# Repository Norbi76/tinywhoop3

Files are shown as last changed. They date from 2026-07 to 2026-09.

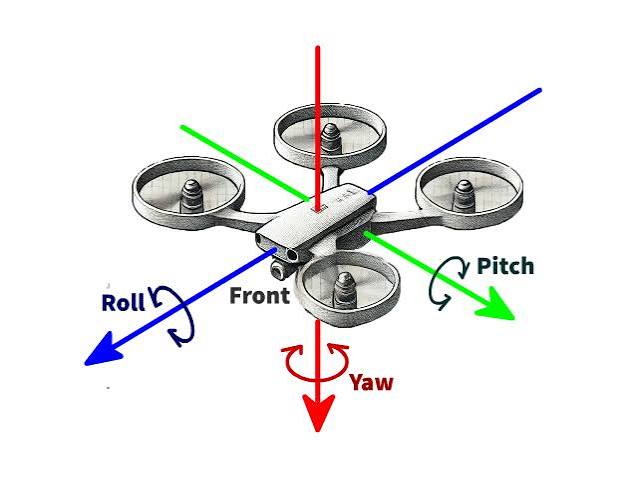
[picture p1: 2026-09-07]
documents/documentatie/images.jpeg

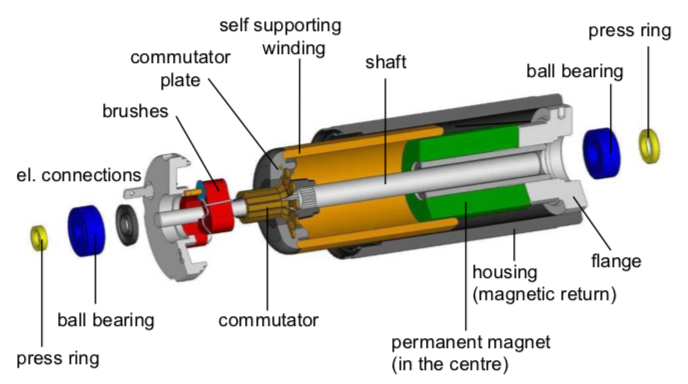
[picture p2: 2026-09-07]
documents/documentatie/Maxon-Coreless-DC-Motor.webp

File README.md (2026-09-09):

Adresa repository: https://github.com/Norbi76/tinywhoop3.git

Pentru a putea compila proiectele este necesara instalarea ESP IDF v6.0.2 !!
Fiecare dintre cele 2 proiecte se va compila si scrie pe micro separat.
Mediul de dezvolatare ESP IDF a fost utilizat pe Linux(Ubuntu).

Pasii pentru compilare si scriere: 
1. cd ~/.espressif/v6.0.2/esp-idf
2. . ./export.sh
3. cd tinywhoop3/flight_controller/ sau cd tinywhoop3/telemetry_module/ 
4. idf.py set-target esp32s3
5. idf.py build flash monitor

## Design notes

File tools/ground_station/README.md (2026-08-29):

# PID ground station

A desktop tuning tool for the eight cascaded PID loops on the flight controller. It plots one
loop's setpoint, measurement, error, individual P/I/D contributions and output in real time, and
reads and writes that loop's gains live over the drone's Wi-Fi AP.

USB is not an option in flight. Everything here goes over UDP through the telemetry module.

## How it connects

```
flight_controller  --UART 460800, framed--  telemetry_module  --UDP 14550, Wi-Fi--  this tool
```

The telemetry module does not interpret the tuning messages. It forwards every UART frame it
receives into a UDP datagram, and splits every inbound datagram back into UART frames. The web
dashboard on `http://192.168.4.1/` keeps working exactly as before and is completely independent
of this tool - you can run both at once.

**Peer discovery**: the module has no idea where you are until you talk to it. Any packet you send
latches your address as its telemetry peer, and a keepalive goes out once a second to keep it
fresh. That is why you can restart this tool, or drop and rejoin the Wi-Fi, without touching the
drone.

## Running it

```bash
pip install -r requirements.txt
```

Join the drone's Wi-Fi AP — the credentials are `WIFI_AP_SSID` / `WIFI_AP_PASSWORD` in
[`telemetry_module/components/wifi_ap/include/wifi_ap.h`](../../telemetry_module/components/wifi_ap/include/wifi_ap.h),
currently `TinyWhoopAP` / `whoop12345`. Then:

```bash
python3 gs.py
```

The link indicator in the top bar goes green within a second or two of the first datagram. If it
stays red: check you are on the drone's AP and not your house network, and check the module's
console for `Ground station link listening on UDP 14550`.

## What each plot means

Selecting a loop's tab subscribes the drone's debug stream to that loop and pulls its live gains
into the editors. Three plots, X-linked so a feature lines up across all three:

1. **Setpoint and measurement** — what the loop was asked for against what it got. This is the
   plot you tune by. A measurement that lags, oscillates around, or never reaches the setpoint
   tells you which term needs work.
2. **Error** — `setpoint - measurement`, with a zero line. The error is not transmitted; it is
   computed here, because at 500 Hz those four bytes are a fifth of the link budget for something
   the receiver already knows.
3. **P, I, D and output** — the individual contributions, plus the post-clamp output. This is
   where you see *why* the loop is behaving as it does: a D term that is mostly noise means the
   derivative cutoff is too high; an I term that dominates means Ki is too large or the loop is
   winding up; an output pinned to its limit means no gain change will help until that is fixed.

The statistics panel updates about four times a second:

| Readout | Meaning |
|---|---|
| `rate` | Sample rate actually arriving, from the sample timestamps. Well below the expected figure means frames are being dropped. |
| `RMS err` / `peak err` | Tracking quality over the visible window. |
| `out sat` | Percentage of samples with `PID_FLAG_OUT_SAT` — the output hit its clamp. Anything sustained here means the loop has no authority left. |
| `I clamped` | Percentage with `PID_FLAG_I_CLAMPED` — the integrator hit its limit or anti-windup froze it. |
| `overshoot` | Peak excursion past the setpoint after a detected step, as a percentage of the step size. |
| `settle 5%` | Time from the step until the measurement stayed inside ±5% of it. |

The last two are the point of the tool. Use the **test signal** group to produce them: a *doublet*
(+A for half a period, −A for half a period, then nothing) is the one to use in the air, because it
excites the loop in both directions and leaves the aircraft where it started. A *step* gives the
cleanest numbers but displaces the drone. A *square* alternates continuously, for watching the
loop settle repeatedly.

## Why a plot can be empty

A loop publishes samples only on the iterations it actually runs, so an empty plot usually means
the loop is not executing rather than that the link is down. Check the link indicator first — if
it is green, the loop is simply not being called:

| Loop | Runs only when |
|---|---|
| `rate_*`, `ang_*` | Armed **and** throttle above the idle cutoff. `flight_control_update()` returns early on every disarmed path and while the throttle is on the floor. |
| `alt` | Altitude hold engaged **and** `nav.altitude_valid` — so the ToF must be fitted and reading. |
| `vel_x`, `vel_y` | Position hold engaged **and** `nav.velocity_valid` — so the optical flow sensor must be fitted and seeing texture. |

This is the intended behaviour, not a limitation: the outer loops self-disengage the instant their
sensor stops being trustworthy, and the inner loops are held off while disarmed so the integrators
cannot wind up against the ground.

## Tuning order

**Work from the inside out. Never tune an outer loop before the loop beneath it is solid** — an
outer loop is measuring the response of the inner loop, so tuning it against a bad inner loop just
bakes the inner loop's error into the outer loop's gains.

1. **Rate loops** (`rate_roll`, `rate_pitch`, `rate_yaw`) — props off first, then on a tether.
   Raise Kp until it oscillates, back off about 30%, then add D until the oscillation damps, then
   a little I to remove steady-state droop.
2. **Angle loops** (`ang_roll`, `ang_pitch`) — P only to begin with. These command rate setpoints,
   so their behaviour is meaningless until step 1 is done.
3. **Velocity loops** (`vel_x`, `vel_y`) — needs the optical flow sensor working and
   `velocity_valid` set.
4. **Altitude** (`alt`) — last, and needs the ToF working.

Applying gains **resets that loop's integrator to zero**. This is deliberate: raising Ki with a
stale accumulator dumps it into the output as a step, and on a 50 g quad that step is the ceiling.
It also means "apply on edit" (off by default) resets the integrator on every spinbox increment —
leave it off while flying.

A **zero in any of the three limit fields** (`I limit`, `Out limit`, `D cutoff`) means "leave this
one as it is", not "set it to zero". Kp/Ki/Kd are different — a zero gain there is applied, because
zeroing a gain is a normal thing to want. The limits are guarded because a zero output limit would
clamp that loop's output to zero for the rest of the flight, and the usual way to send one is by
accident: applying before a read-back has landed, or loading a profile that only carries kp/ki/kd.

> **Unit note:** the `alt` loop is labelled m/s here to match the loop table it was specified
> against, but the firmware runs it as a *position* loop — `altitude_setpoint` is in **metres**
> (clamped 0.05–1.20 m) and the measurement is `nav.altitude`. So on the `alt` tab an inject
> amplitude of `5.0` is five metres, not five m/s, and the axis labels read m/s for a metres
> signal. `MAX_CLIMB_RATE_MS` only governs how fast the throttle stick slews that setpoint.

## Bandwidth: why only one loop streams at full rate

The UART between the two boards is 460800 baud, 8N1, so 46080 bytes/second. A debug frame is 30
bytes of payload plus 8 bytes of framing = **38 bytes**. The status frame (61 B at 50 Hz) and the
IMU frame (44 B at 10 Hz) are always present, costing 3490 B/s before any tuning traffic.

| Case | Debug traffic | With baseline | Link used |
|---|---|---|---|
| All 8 loops at 50 Hz | 15200 B/s | 18690 B/s | **41%** |
| `rate_roll` alone at 500 Hz | 19000 B/s | 22490 B/s | **49%** |

Half the link for one loop is why the tab you are looking at is the only one streaming at rate.
Streaming all three rate loops at 500 Hz would be 57000 B/s — more than the UART can carry, and
the frames would simply be dropped at the flight controller's queue rather than arriving late.

### The overview tab is not uniform, and cannot be

The overview tab selects `PID_LOOP_ALL` with one divider. But the loops do not tick at the same
rate — the decimation counter counts *that loop's* ticks — so a single divider gives different
sample rates per loop. At the divider of 20 the overview uses:

| Loops | Loop rate | Sample rate |
|---|---|---|
| `rate_roll`, `rate_pitch`, `rate_yaw` | 1000 Hz | 50 Hz |
| `ang_roll`, `ang_pitch` | 250 Hz | 12.5 Hz |
| `alt`, `vel_x`, `vel_y` | 50 Hz | 2.5 Hz |

The overview is for spotting which loop is misbehaving, not for measuring one. Open that loop's
own tab to get it at full rate.

## Arming, and why KILL is the only reliable button

**The telemetry module sends its own control frame at 50 Hz whether or not you are here**, and the
flight controller acts on whichever frame arrived most recently. So an ARM or DISARM request from
this tool is overwritten within 20 ms by whatever the web dashboard is asking for. The ARM toggle
is advisory — use the dashboard for arming.

**KILL is different, and it is reliable**: the flight controller *latches* the kill flag. One frame
that gets through cuts the motors and keeps them cut, and the latch only clears once a frame
arrives requesting neither kill nor arm (i.e. once the dashboard's arm toggle is also off). The
button repeats for 500 ms purely as insurance against a lost datagram.

Battery reads a constant nominal voltage with no percentage. There is no ADC divider on the pack,
so `flight_control_get_status()` reports a fixed 3.8 V and the flight controller never sends a
battery frame. This tool parses both message types, so it will start reporting real numbers the
moment sensing is fitted — nothing here needs changing.

## Flight logging

The **REC** button in the top bar records the whole flight to one file:
`flight_<date>_<time>.ndjson` in the working directory. This is a different thing from the
per-loop **log to CSV** checkbox — that one captures a single PID loop for tuning, this one
captures the flight. Both can be on at once.

What goes in, and where each stream comes from:

| Record | Rate | Contents |
|---|---|---|
| `header` | once | when, the gains on every loop at the moment recording started, which tab was open |
| `status` | 50 Hz | the flight controller's own view: attitude, altitude, climb, body velocity, all four motor outputs, loop rate, mode, flags |
| `control` | 50 Hz | **what the pilot commanded** — the frame the telemetry module sent the flight controller |
| `pid` | 50 Hz | the streaming loop's setpoint, measurement, P/I/D and output, thinned from up to 500 Hz |
| `link` | 1 Hz | packet rate and online/offline, so a bad radio moment is visible as itself |
| `event` | — | arming, kill, mode and gain changes, tab selections, link transitions, your markers |
| `footer` | once | on a clean stop. **Its absence means the session died**, which the report tells you |

About 1.5 MB per minute. Newline-delimited JSON, one record per line, appended as you fly — so a
log from a session that ended in a crash is still readable right up to the moment it stopped. That
is the reason for the format, and it is why recording is **always plain text**: a gzip stream
buffers inside the compressor, so a log killed mid-flight would be entirely unreadable rather than
readable up to the last line. Gzip them afterwards if you want to keep a lot — everything that
reads a log opens `.ndjson.gz` transparently.

### The control echo, and why it needed a firmware change

The ground station used to see only what the drone *reported*. The control frame is built and
sent by the telemetry module, so nothing on this side ever knew what the pilot had asked for —
and a log showing the drone rolling right is ambiguous until you can see whether roll right was
being commanded.

`uart_link.c` now echoes every outgoing control frame to the ground station. It costs nothing on
the UART that flies the drone (the frame is already sent by then) and 1.15 kB/s on Wi-Fi. It goes
through a queue rather than straight into `gs_link_forward()`, because that function's batch
buffer is lock-free *on the condition* that only the RX task touches it.

Each echo carries its own sequence number, so the ground station can tell when command frames
were lost in transit. Gaps are recorded as `control_gap` events and the report prints them —
which matters, because the command-versus-actual section refuses to pair a status frame with a
command more than 0.2 s old. A hole in the command trace is the one thing that could make that
section draw a confident wrong conclusion, so it excludes what it cannot pair and says how much.

**A module running older firmware simply never sends these.** Everything still records; the log
just has no command trace, and the report says so instead of guessing.

### Markers

**M** — or the MARK button — stamps the current instant. Press it the moment something looks
wrong; you do not need to be looking at the screen, and the report lists markers first, so it is
where you start reading afterwards. **Shift+M** adds a typed note, which opens a modal dialog and
is therefore for use on the ground.

### Reading a log back

The **replay** tab opens one: attitude with the commanded angles dashed over it, altitude against
throttle demand, body velocity, and all four motors — X-linked, with armed periods shaded, kills
shaded red, and your markers drawn across every plot. The report sits beside the plots, and
**copy report** puts it on the clipboard.

Stopping a recording loads it into the replay tab automatically.

Without the GUI, and without needing PyQt6, numpy or pyqtgraph installed at all:

```bash
python3 logtool.py flight_20260827_181500.ndjson       # the report
python3 logtool.py flight.ndjson --slice 41.0 48.5     # just that window
python3 logtool.py flight.ndjson --events              # just the timeline
python3 logtool.py flight.ndjson --csv flight.csv      # status stream for a spreadsheet
```

### What the report actually tells you

It is built around separating causes that look identical from the air:

- **Link first.** A gap in the downlink explains everything after it, so nothing else is worth
  reading across one. It also flags the flight controller reporting its *own* control link
  unhealthy — a different link, and the one that disarms you after 300 ms.
- **How each arm session ended** — the pilot letting go, a KILL (and from which of the two places
  it can come), or a watchdog. These are indistinguishable in the status stream alone.
- **Command versus actual**, including a "hands off" figure: the mean attitude over every frame
  where roll and pitch were commanded within a degree of level. A drone holding a tilt while
  being asked to stay level is a trim or balance problem, and no gain change fixes it.
- **Motor balance.** At a steady hover the four outputs should sit close together. A spread wider
  than 15% is called out, with which corner is working hardest — that corner is the one being
  held up, so the airframe is falling towards the opposite one. Cross-check it against the drift
  direction above.
- **Sensor validity as a percentage of armed time**, next to what each flag gates. "POS HOLD did
  nothing" is almost always `velocity_valid` never being set, and that is invisible unless you
  look for it.
- **Per-loop saturation and integrator clamping.** A loop pinned at its output limit cannot be
  fixed by tuning it, and it is worth knowing that before spending an evening trying.

Where a number cannot be computed the report says so rather than printing a default that reads
like a measurement.

## Gain profiles

Gain profiles save and load all eight loops to a JSON file. **Loading only fills the editors** —
nothing is sent until you press apply on a tab, because pushing eight gain sets at once would
reset every integrator on the drone.

## Files

| File | What it holds |
|---|---|
| `protocol.py` | Struct formats, message ids and the `LOOPS` table. Mirrors `telemetry_uart.h` — change both together. |
| `link.py` | UDP socket, receive thread, keepalive thread, per-loop numpy ring buffers. |
| `panels.py` | The per-loop tuning panel, the overview panel and the replay panel. |
| `gs.py` | Main window, tab handling, top bar, recording controls, entry point. |
| `flightlog.py` | The flight recorder and the reader. No Qt, no numpy. |
| `flightreport.py` | Turns a log into the text report. Standard library only. |
| `logtool.py` | Command-line front end to the two above. |

Two invariants worth keeping if you edit this:

- **Never redraw from the receive thread.** One 30 Hz timer on the GUI thread drives everything.
- **The ring buffers are preallocated numpy arrays, not lists of tuples.** At 500 Hz a
  list-of-tuples allocates tens of thousands of short-lived objects a minute, and the resulting GC
  pauses are visible as stutter in the plots.
- **Nothing on the receive thread may block.** The flight recorder is called from the middle of
  the socket loop and only ever appends to an in-memory queue; a separate writer thread does the
  disk I/O. A stalled write there would show up as lost telemetry, not as a slow log.

`flightlog.py`, `flightreport.py` and `logtool.py` deliberately import none of PyQt6, numpy or
pyqtgraph, so a log can be read on a machine that has none of them installed.

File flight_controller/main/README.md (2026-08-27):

# `main` — startup, task layout and the telemetry link

The flight controller's entry point. This directory contains no control logic of its own — it
creates the three FreeRTOS tasks, brings the components up in the right order, and owns the
cross-task plumbing that lets a 1 kHz loop, a 100 Hz loop and a 50 Hz loop share data without any
of them blocking the others.

## The three tasks

| Task | Core | Priority | Rate | Job |
|---|---:|---:|---:|---|
| `fc_task` | 1 | `configMAX_PRIORITIES - 1` | 1000 Hz | The entire control loop: IMU read → attitude → nav snapshot → cascade → motors |
| `sensor_task` | 0 | 6 | 100 Hz | ToF (every 3rd cycle) + optical flow (every cycle) → `nav_estimator` → publish `nav_state_t` |
| `telemetry_task` | 0 | 5 | 50 Hz | Status frame, PID debug drain, IMU frame every 5th cycle, drain all inbound frames |

The split is by **timing sensitivity**, not by subject matter.

- `fc_task` gets core 1 (`APP_CPU`) because core 0 (`PRO_CPU`) runs Wi-Fi, lwIP and other ESP-IDF
  background work. Nothing slow — I²C clock stretching, SPI, UART, logging — is allowed in it once
  it is past startup.
- `sensor_task` is on core 0 specifically **because** its sensors are slow blocking I/O. Letting
  either of them into `fc_task` would cause it to miss its 1 ms deadline.
- `telemetry_task` is on core 0 for the same reason.

## Startup order in `app_main()` — and why it is this order

```
 1. imu_data_mutex, imu_ready_semaphore
 2. motor_driver_init()          <- FIRST. Motors driven to zero before anything can command thrust.
 3. attitude_init(1/1000, 0.5)
 4. flight_control_init()        <- creates the 8 PIDs, binds them to pid_registry
 5. uart_telemetry_init()        <- UART1, TX GPIO6 / RX GPIO7, 460800 baud
 6. xTaskCreatePinnedToCore(fc_task, core 1)
       └─ fc_task: imu_setup() -> imu_calibrate_acc() -> imu_calibrate_gyro()
                   -> give(imu_ready_semaphore) -> enter 1 kHz loop
 7. take(imu_ready_semaphore, 30 s)   <- app_main BLOCKS here
 8. sensor_task_init() + sensor_task_start(core 0)
 9. xTaskCreatePinnedToCore(telemetry_task, core 0)
```

**Step 2 must be first.** `motor_driver_init()` configures the LEDC channels with duty 0 before
any code path exists that could command thrust. (This does *not* protect against the gates
floating between chip reset and this line — that needs physical pull-downs; see the
`TODO(hardware)` in `motor_driver.c`.)

**Steps 7–8 are the interesting bit.** The ToF sensor attaches to the I²C bus that `imu_setup()`
*creates*, so touching it first would race the bus. Rather than calling `imu_setup()` from
`app_main`, the design lets `fc_task` own the IMU end to end and signals readiness with a binary
semaphore.

The 30-second timeout is sized deliberately: accel calibration is 500 samples at 2 ms, the gyro
sweep is 1000 samples and may retry up to three times if it detects motion. At a 1 kHz tick the
2 ms delay rounds up and the I²C read adds ~0.5 ms, so each sweep is nearer 3 s than 2 s — about
11 s worst case. 30 s leaves room without the ToF ever starting mid-calibration.

If the semaphore times out, navigation sensors simply never start and the drone flies in angle
mode. Consistent with everything else here: **no non-fatal failure grounds the aircraft.**

## `fc_task` — the 1 kHz loop

```
  imu_read_raw_data()            ← fails: motor_all_stop(), 10 ms backoff, retry
  imu_convert_raw_to_physical()
  compute dt from esp_timer      ← clamped: dt outside (0, 0.02] is replaced with 1 ms
  imu_compute_roll_pitch()
  publish latest_imu_payload     ← zero-timeout mutex; skipped if busy
  attitude_update() / attitude_get()
  sensor_task_get_nav_state()    ← zero-timeout mutex; keeps last copy if busy
  flight_control_update()        ← the cascade; writes the motors
  vTaskDelayUntil(1 ms)
```

Three things worth calling out:

**A dead IMU stops the motors.** No attitude means the drone must not be flying, so a failed read
calls `motor_all_stop()` and backs off rather than continuing on stale data.

**`dt` is clamped.** A scheduling hiccup producing a huge `dt` would give the cascade a huge
derivative and integrator step. Anything outside `(0, 0.02]` is replaced with the nominal 1 ms.

**Every cross-task read uses a zero timeout.** `fc_task` never blocks on `sensor_task` or
`telemetry_task`. A `nav_state_t` copy up to one 100 Hz cycle stale, or an IMU telemetry frame
that skips one publish, is always preferred over a missed 1 ms deadline.

> There is a comment in `fc_task` worth knowing about: the loop period used to be
> `pdMS_TO_TICKS(1000)` — 1000 ms — so the "1 kHz" loop was actually running at 1 Hz. It is
> `pdMS_TO_TICKS(1)` now, and that only works because `CONFIG_FREERTOS_HZ` is 1000 in
> `sdkconfig.defaults`. If the tick rate ever drops back to the IDF default of 100 Hz, this loop
> silently becomes a 100 Hz loop.

## `sensor_task` — the 100 Hz nav loop (`sensor_task.c`)

Reads attitude (for tilt and rotation compensation), polls the two nav sensors, feeds
`nav_estimator`, and publishes the result behind `nav_state_mutex`.

**ToF every 3rd cycle (~33 Hz).** The sensor is configured for a 25 ms inter-measurement period
(~40 Hz), so polling every 100 Hz cycle would mostly return "not ready" — wasted I²C transactions
on a bus the 1 kHz IMU loop is also using.

**Flow every cycle (100 Hz).** No internal rate limit on that sensor.

**A failed read passes `NULL`, not nothing.** Both `nav_estimator_update_*` calls happen either
way. Passing `NULL` is how the estimator is told "no data this cycle" so it can run its own 200 ms
timeout and eventually drop the validity flag — rather than silently freezing the last good
altitude forever.

**Neither sensor is required.** `sensor_task_init()` logs a warning and carries on if either
`vl53l1x_init()` or `pmw3901_init()` fails. `sensor_task_init()` only returns an error if the
*mutex* could not be created.

### The `nav_state_t` handoff

Two different timeouts on the same mutex, and the asymmetry is the design:

| Side | Call | Timeout | On failure |
|---|---|---|---|
| Writer (`sensor_task`, 100 Hz) | `xSemaphoreTake(..., 2 ms)` | 2 ms | Skip this publish |
| Reader (`fc_task`, 1 kHz) | `sensor_task_get_nav_state()` | **0** | Keep last copy, return false |

The reader must never wait. The writer can afford 2 ms out of its 10 ms budget.

## `telemetry_task` — the 50 Hz link

**Transmit order matters.** Status frame first, then PID debug samples, then the IMU frame:

1. **Status, every cycle.** This is what the dashboard reads and what the *telemetry module's*
   view of the link depends on, so it goes out first regardless of how much tuning traffic is
   queued behind it.
2. **PID debug, up to `PID_DEBUG_PER_CYCLE` (32) per cycle.** 32 × 50 Hz = 1600 samples/s,
   comfortably above the 500 Hz the ground station asks for at its fastest setting, so the queue
   only backs up if the UART itself is the bottleneck. The drain is zero-wait and bounded — an
   empty queue ends the loop immediately, which is the normal case. Send failures here are
   deliberately **unlogged**: this runs up to 32 times per cycle and a per-sample log line would
   saturate the console UART on its own.
3. **IMU frame, every 5th cycle (10 Hz).** Not needed for control; kept for logging and the raw
   data view.

**Receive drains everything queued**, not one frame per cycle — otherwise the RX buffer backs up
and the control frames actually acted on get progressively staler. It uses
`uart_telemetry_read_message_resync()`, which discards one bad frame instead of flushing the whole
buffer; a flush would drop good control frames and trip the flight controller's own 300 ms link
watchdog.

### Inbound message handling

| Message | Action |
|---|---|
| `TELEMETRY_MSG_CONTROL` | `flight_control_set_control_input()` — feeds the controller **and** pets the link watchdog |
| `TELEMETRY_MSG_GAINS` | `flight_control_set_gains()` (dashboard path — preserves integrators) |
| `TELEMETRY_MSG_PID_GAINS` | All six floats zero → read request, answer with `pid_registry_read_gains()`. Otherwise `pid_registry_apply_gains()` (ground-station path — resets the integrator) |
| `TELEMETRY_MSG_PID_SELECT` | `pid_registry_set_stream()` |
| `TELEMETRY_MSG_PID_INJECT` | `pid_registry_set_inject()` |

Every handler length-checks `payload_len` against the struct before casting the payload. That is
the only thing standing between a truncated frame and a read past the end of the payload buffer.

## Hardware configuration set here

| Item | Value | Status |
|---|---|---|
| Telemetry UART | `UART_NUM_1`, 460800 baud | |
| TX / RX | GPIO 6 / GPIO 7 | **`TODO(pins)`** — unconfirmed |
| Attitude `tau` | 0.5 s | Starting value |
| `fc_task` stack | 4096 | |
| `telemetry_task` stack | 4096 | |

> **Pin conflict to be aware of:** the telemetry module's side of this link is currently
> configured for GPIO 43/44 in `telemetry_module/components/uart_link/include/uart_link.h`. Both
> ends are marked TODO and neither has been confirmed against the harness. The pins do not have to
> match numerically (they are different boards), but both must match the actual wiring.

## Timing and concurrency summary

| Shared state | Writer | Reader | Mechanism |
|---|---|---|---|
| `latest_imu_payload` | `fc_task` (1 kHz) | `telemetry_task` (10 Hz) | `imu_data_mutex` — writer 0 timeout, reader 1 ms |
| `shared_nav_state` | `sensor_task` (100 Hz) | `fc_task` (1 kHz) | `nav_state_mutex` — writer 2 ms, reader **0** |
| `control_input` | `telemetry_task`, core 0 | `fc_task`, core 1 | `portMUX` spinlock, inside `flight_control` |
| PID debug samples | `fc_task` | `telemetry_task` | FreeRTOS queue, zero-timeout send that drops |
| `imu_ready_semaphore` | `fc_task` | `app_main` | Binary semaphore, 30 s timeout |

The rule throughout: **the 1 kHz side never waits.** Every mechanism above is arranged so the
worst case for `fc_task` is stale data, never a blocked tick.

## Files

| File | Contents |
|---|---|
| `main.c` | `app_main()` startup ordering, `fc_task`, `telemetry_task`, the IMU telemetry mutex. |
| `sensor_task.c` | The 100 Hz nav task, sensor init (non-fatal), the `nav_state_t` publish/copy pair. |
| `sensor_task.h` | Three public functions and the "neither sensor is required" contract. |
| `CMakeLists.txt` | Component registration — `main` depends on every other component. |

## See also

Component READMEs: [`imu_driver`](../components/imu_driver/README.md) ·
[`attitude_estimator`](../components/attitude_estimator/README.md) ·
[`nav_estimator`](../components/nav_estimator/README.md) ·
[`flight_control`](../components/flight_control/README.md) ·
[`pid_registry`](../components/pid_registry/README.md) ·
[`motor_driver`](../components/motor_driver/README.md) ·
[`vl53l1x_driver`](../components/vl53l1x_driver/README.md) ·
[`pmw3901_driver`](../components/pmw3901_driver/README.md) ·
[`telemetry_uart`](../../shared_components/telemetry_uart/README.md)

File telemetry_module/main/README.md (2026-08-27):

# `main` — startup ordering and core assignment

`app_main()` and nothing else. Every subsystem lives in a component; this file's only job is to
bring them up in the right order and put them on the right core.

Both of those are load-bearing, which is why this is a README rather than a footnote.

## Core assignment

| Core | What runs there |
|---:|---|
| **0** | Wi-Fi + lwIP (the IDF pins them here anyway), the HTTP server, both UART tasks, `gs_link` |
| **1** | The camera capture task, **alone** |

**Why the whole control path is on one core.** The 50 Hz UART transmit cadence and the 20 Hz
dashboard input POSTs are two halves of the same loop. Putting them on one core means one
scheduler arbitrates between them, with priorities that actually mean something and no cross-core
latency in between.

**Why the camera is isolated.** Grabbing a UXGA JPEG out of PSRAM and pushing it through FATFS
onto an SD card is a long, bursty, blocking job. On the other core, a slow card cannot delay a
control frame no matter how long it takes.

Priorities on core 0, highest first:

```
  7  UART TX       missing a slot risks the flight controller's 300 ms watchdog
  6  UART RX       a late status frame only makes the dashboard stale
  5  HTTP server   serving the dashboard must never delay a control frame
  4  gs_link       a stalled ground station must never delay anything
  ----------------------------------------------------------------------
  3  camera task   (core 1)
```

That ordering is a single consistent statement: **the closer something is to keeping the drone
armed and controllable, the higher it sits.**

## Startup order

```
 1. control_state_init()                      FATAL
 2. uart_link_init() + uart_link_start(0)     FATAL
 3. camera_sd_init() + start_task(1)          non-fatal
 4. wifi_ap_init()                            FATAL
 5. gs_link_start()                           non-fatal
 6. http_server_start()                       FATAL
```

Each position is chosen, not incidental:

1. **`control_state` first** so every later module has somewhere valid to read from and write to.
   It depends on nothing.
2. **UART link before Wi-Fi.** This is the link that actually flies the drone. If it cannot come
   up there is no point serving a dashboard.
3. **Camera and SD third, non-fatal.** Photography is the mission, but flight is the prerequisite.
   A missing card or a failed camera probe is logged, surfaced on the dashboard, and otherwise
   ignored. The capture task is started **even if init partly failed** —
   `camera_sd_request_capture()` rejects requests on its own when the hardware is missing, and
   having the task running keeps the shutdown paths uniform.
4. **Wi-Fi AP fourth**, because everything after it needs a network.
5. **`gs_link` after the AP** so lwIP has a netif to bind its UDP socket to. Non-fatal for the same
   reason as the camera: it is a tuning tool, not a flight requirement.
6. **HTTP server last**, because it is the thing that starts accepting pilot input, and everything
   it touches has to exist before the first request arrives.

## Fatal vs non-fatal

The split is consistent and worth stating explicitly:

| Fatal (returns from `app_main`) | Non-fatal (logs and continues) |
|---|---|
| `control_state`, `uart_link`, `wifi_ap`, `http_server` | `camera_sd`, `gs_link` |

**Anything the pilot needs in order to fly is fatal. Anything that only makes the drone more
useful is not.** The same principle appears on the flight controller side, where the ToF and
optical flow sensors are non-fatal and their loops simply disengage.

## What the log tells you at the end

```
Startup complete.
  Connect to Wi-Fi 'TinyWhoopAP' and open http://192.168.4.1/
  Camera: OK   SD card: OK
```

That last line is the quickest way to tell whether a capture session is going to work before you
take off — it is also mirrored into `/api/status` as `camera_ok` / `sd_ok`.

## Files

| File | Contents |
|---|---|
| `main.c` | `app_main()`, the core-assignment comment, the six init steps. |
| `CMakeLists.txt` | Depends on all six components. |

## See also

Component READMEs: [`control_state`](../components/control_state/README.md) ·
[`uart_link`](../components/uart_link/README.md) ·
[`gs_link`](../components/gs_link/README.md) ·
[`wifi_ap`](../components/wifi_ap/README.md) ·
[`http_server`](../components/http_server/README.md) ·
[`camera_sd`](../components/camera_sd/README.md) ·
[`telemetry_uart`](../../shared_components/telemetry_uart/README.md)

Development without hardware: [`../tools/mock_server.py`](../tools/mock_server.py).

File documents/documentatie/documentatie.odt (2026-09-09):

DEZVOLTAREA UNUI SISTEM DE CONTROL DE ZBOR ȘI CAPTURĂ DE IMAGINI AERIENE PENTRU DRONE

Candidat: Norbert KONDORA

Coordonator științific: Dr. Habil. Ing. Mihai V. MICEA

Sesiunea: Septembrie 2026

REZUMAT

Lucrarea de față descrie proiectarea, implementarea unui sistem de control de zbor pentru o dronă construită integral de la zero, precum și al unui subsistem dedicat capturii și salvării de imagini aeriene. Arhitectura hardware a sistemului este împărțită pe două plăci de dezvoltare ESP32-S3 astfel: un controler de zbor, responsabil pentru stabilizarea dronei și un modul de telemetrie care asigură interfața de control utilizată de pilot, printr-o pagina web disponibilă prin Wi-Fi, precum și achiziția, procesarea și salvarea pe un card de memorie a imaginilor capturate cu modulul cameră compatibil. Comunicarea între cele două plăci se realizează printr-un protocol serial simplu iar structura mesajelor este implementată într-un modul software partajat între cele două proiecte ESP-IDF corespunzătoare pentru fiecare dintre cele două module de dezvoltare.

# Introducere

## Contextul temei alese

Dronele au devenit în ultimii ani instrumente obișnuite într-o multitudine de domenii: cartografiere, inspectia cladirilor și a instalatiilor industriale, agricultură, filmare și fotografiere aeriană. Majoritatea acestor aplicații se bazează insa pe un lucru pe care îl luăm ca atare anume, semnalul GPS folosit pentru pozitionarea dronei.

În interiorul cladirilor, în apropierea structurilor metalice sau în spatii închise, nu ne putem baza pe acest semnal deoarece este imprecis în conditiile de mentionate mai sus. Zborul în astfel de condiții rămâne o problemă distinctă și dificilă, care presupune alte metode pentru determinarea și mentinerea pozitiei.[1] Dronele de dimensiuni mici, capabile sa zboare în spații inchise, formeaza astfel o categorie aparte, cu cerințe proprii atât la nivel hardware, cat și la nivel software.

## Motivația și scopul proiectului

Motivația acestei lucrări a pornit din dorința de a înțelege, cât mai profund, cum funcționează un sistem care menține echilibrul și poziția unei drone și de a parcurge personal tot procesul de dezvoltare.

La aceasta se adaugă un obiectiv concret: capturarea de imagini aeriene destinate reconstrucției tridimensionale a unui obiect sau a unei încăperi. Această utilizare impune cerinte diferite de cele ale unei drone obișnuite cu capabilitati de fotografiere/filmare. Imaginile trebuie realizate în coditii de iluminare cat mai constante intre cadrele obtinute, altfel programele de reconstructie interpretează variatiile de luminozitate ca modificari ale scenei reale iar rezultatul se degradează.[2]

Scopul lucrarii este, prin urmare, proiectarea, implementarea și testarea unei drone complete, construite de la zero, folosind componente ieftine și larg disponibile.

## Soluția propusă

Soluția propusă are ca element central o alegere arhitecturală: drona folosește două microcontrolere de mici dimensiuni în loc de unul singur.

Primul se ocupă exclusiv de stabilizarea dronei. Citește permanent date de la senzori și reglează turatia celor patru motoare. Al doilea se ocupă de restul sarcinilor: comunicatia cu utilizatorul, camera și salvarea imaginilor pe un card de memorie. Această separare a sarcinilor a fost aleasă cu scopul de a preveni posibile perturbari ale sistemului de control cauzate de intarzieri în transmiterea datelor sau operatii lente precum salvarea unei fotografii pe cardul de memorie.

Comanda dronei se face printr-o rețea WiFi, creată de unul dintre cele două microcontrolere, folosind o pagină web accesibilă dintr-un browser obișnuit. Acestă

alegere elimină nevoia unei telecomenzi specializate și face drona utilizabilă cu dispozitive pe care oricine le are deja.

În paralel cu programul de pe dronă a fost realizata o aplicație separată, cu rol de depanare și validare folosită pentru ajustarea comportamentului dronei, precum și pentru inregistrerea și analiza ulterioară a zborurilor.

## Contribuția autorului

Contribuțiile proprii ale acestei lucrări, asumate de autor, sunt următoarele:

- Scrierea logicii de control, integrarea componentelor software necesare senzorilor, parametrizarea și verificarea experimetală a sistemului.
- Arhitectura cu două microcontrolere separate, cu izolarea completă a functiei de zbor față de restul sistemului, reprezintă o abordare diferită de cea a soluțiilor comparabile analizate în capitolul următor, care execută toate funcțiile pe un singur procesor.
- Comanda prin pagină web, fără un echipament radio dedicat, face drona utilizabilă fără achiziția unei telecomenzi specializate.
- Subsistemul de capturare a imaginilor.
- Instrumentul de analiză dezvoltat în paralel a permis identificarea, pe baza datelor inregistrate în timpul zborului, a unor probleme reale de comportament ale sistemului de control, care altfel ar fi rămas invizibile.

Rezultatul nu este un produs finit. O parte dintre parametrii sistemului de control sunt încă valori estimate, iar câteva verificări practice rămân de efectuat. Lucrarea prezintă onest atât ceea ce funcționează, cât și problemele identificate și rămase deschise, considerând că modul în care acestea au fost descoperite și analizate constituie el însuși un rezultat al proiectului.

# Soluții similare

Dezvoltarea unui sistem de control de zbor propriu se raportează la un ecosistem matur de soluții existente, care acoperă un spectru larg, de la sisteme de pilotare automată de uz profesional până la platforme de cercetare de dimensiuni reduse și proiecte experimentale bazate pe microcontrolere de uz general.

## Sisteme de pilotare automată de uz profesional

Platformele PX4[3] și ArduPilot[4] reprezintă standardul în domeniul sistemelor de pilotare automată open source, fiind utilizate atât în cercetare, cât și în aplicații comerciale. Ambele oferă funcționalități complete de navigație autonomă, planificare de misiune, gestiune a modurilor de zbor și redundanță senzorială, inclusiv suport pentru menținerea poziției în interior pe baza fuziunii dintre un senzor de flux optic și unul de măsurare al distanței.

Aceste sisteme sunt însă proiectate pentru a rula pe platforme hardware dedicate, din familia Pixhawk, construite în jurul unor microcontrolere de clasă superioară și echipate cu unități inerțiale redundante [5]. Volumul codului sursă, cerințele de memorie și complexitatea arhitecturală fac ca aceste soluții să nu fie transferabile pe o placă de dezvoltare de dimensiunea și costul celor utilizate în prezentul proiect.

## Firmware pentru drone de mici dimensiuni

Pentru dronele de mici dimensiuni, categorie în care se încadrează și platforma dezvoltată, soluția dominantă este firmware-ul Betaflight [6]. Acesta este optimizat pentru performanță de zbor manual, cu accent pe latență redusă și pe calitatea răspunsului buclelor de reglare a vitezei unghiulare, și rulează pe controlere de zbor dedicate, construite în jurul microcontrolerelor din familia STM32.

Diferențele față de soluția propusă sunt structurale. Betaflight presupune existența unei legături radio dedicate, cu emițător și receptor specializate, comanda fiind transmisă prin protocoale de radiocomandă consacrate. Subsistemul video, atunci când există, este independent de firmware-ul de zbor: imaginea este transmisă analogic sau digital către ochelarii pilotului, fără a fi procesată sau stocată la bordul aeronavei. Nu există, în consecință, nicio integrare între funcția de zbor și funcția de achiziție de imagini, acestea fiind două sisteme fizic separate care coexistă pe aceeași structură mecanică.

## Soluții bazate pe microcontrolere ESP32

Proiectul ESP-Drone, dezvoltat de Espressif, este cea mai apropiată soluție de tema lucrării: un firmware de zbor pentru microcontrolere din familiile ESP32, ESP32-S2 și ESP32-S3, portat din firmware-ul platformei Crazyflie [7]. Soluția include comandă prin Wi-Fi, dintr-o aplicație mobilă dedicată, iar prin modulul opțional de extensie pentru menținerea poziției utilizează aceeași pereche de senzori: PMW3901 și VL53L1X. Dată fiind această suprapunere, adaptarea acestui proiect la platforma hardware proprie a fost evaluată explicit, ca alternativă la dezvoltarea unui firmware propriu. Analiza a identificat câteva obstacole concrete:

- Mecanismul bazat pe monitorizarea tensiunii acumulatorului - ESP-Drone folosește tensiunea acumulatorului atât în lanțul de distribuție a puterii, cât și în mecanismul de supraveghere a stării aeronavei, o funcționalitate care nu era disponibilă sistemului discutat în acest proiect la momentul evaluării.
- Incompatibilitatea arhitecturală - ESP-Drone folosește un protocol de comunicație diferit, bazat pe Wi-Fi și care este utilizată impreună cu o aplicație mobilă dedicată. Modulul de telemetrie, tabloul de bord web, protocolul serial dintre cele două plăci, driverul pentru unitatea de măsură inerțială și instrumentul de depanare, dezvoltate în cadrul acestei lucrări, nu au nimic în comun cu acea arhitectură.
- Coeficienți de reglare ale buclelor PID diferite - Coeficienții de reglare sunt calibrați pentru structura mecanică diferită, deci ar fi fost necesară oricum o reglare completă, iar dificultățile identificate în timpul testărilor, descrise în capitolul dedicat rezultatelor, provin din parametri specifici acestei construcții, pentru care niciun firmware existent nu oferă valori.

Proiectul a fost folosit, în schimb, ca implementare de referință: modul în care măsurătoarea de flux optic este corectată cu viteza unghiulară măsurată de giroscop, precum și configurarea telemetrului laser, au fost comparate cu soluția adoptată acolo.

# Fundamente teoretice

În acest capitol sunt prezentate noțiunile teoretice pe care se bazează sistemul realizat, împreună cu uneltele și bibliotecile folosite. Pentru fiecare noțiune este prezentat și modul concret în care aceasta apare implementată.

## Principiul de zbor al unei drone cu patru motoare

La baza funcționării unei drone se află Principiul al 3-lea al Mecanicii lui Newton: pentru fiecare acțiune, există o reacție egală și de sens opus. Mai exact, pe măsură ce elicele dronei împing aerul în jos, ele creează o forță de portanță în sus. În consecință, această forță de portanță permite dronelor să plutească, să urce sau să coboare cu o precizie remarcabilă. Mai mult, prin reglarea vitezei elicelor, dronele își pot controla mișcările și își pot menține stabilitatea în timpul zborului.[8]

Pentru a înclina drona într-o parte, motoarele de pe acea parte trebuie să producă mai puțină forță decât cele de pe partea opusă. Diferența dintre forțe creează un moment care rotește drona iar, ca urmare a înclinării, aceasta se deplasează pe axa de translație corespunzătoare. La fel se obține și înclinarea față-spate. Rotația în jurul axei verticale funcționează pe alt principiu. Când o elice se rotește într-un sens, apare un moment de reacție care acționează asupra dronei în sensul opus. Din acest motiv două dintre elice, aflate pe aceeași diagonală, se rotesc în sens orar și două, aflate pe cealaltă diagonală, se rotesc în sens antiorar, astfel încât în zbor normal aceste forțe se anulează reciproc. Dacă accelerăm perechea care se rotește antiorar și le încetinim pe celelalte două, drona se va roti în sens orar.


Figura 1 – Principalele mișcări ale unei drone(sursa: [8])

Cele trei comenzi de rotație, ruliu(roll), tangaj(pitch) și girație(yaw) împreună cu comanda de propulsie, trebuie transformate în patru valori individuale, câte una pentru fiecare motor. Această operație este denumită în practică mixare și este implementată astfel:

mix[MOTOR_FRONT_LEFT] = roll - pitch - yaw;

mix[MOTOR_FRONT_RIGHT] = -roll - pitch + yaw;

mix[MOTOR_REAR_LEFT] = roll + pitch + yaw;

mix[MOTOR_REAR_RIGHT] = -roll + pitch - yaw;

Semnele din fiecare coloană rezultă din poziția motorului și din sensul lui de rotație. Pentru înclinarea laterală, motoarele din stânga primesc semnul plus, iar cele din dreapta semnul minus, astfel încât o comandă pozitivă ridică partea stângă. Pentru înclinarea față-spate, motoarele din spate primesc plus. Pentru rotația pe verticală semnele urmează sensul de rotație al elicei: motoarele care se rotesc antiorar primesc plus.

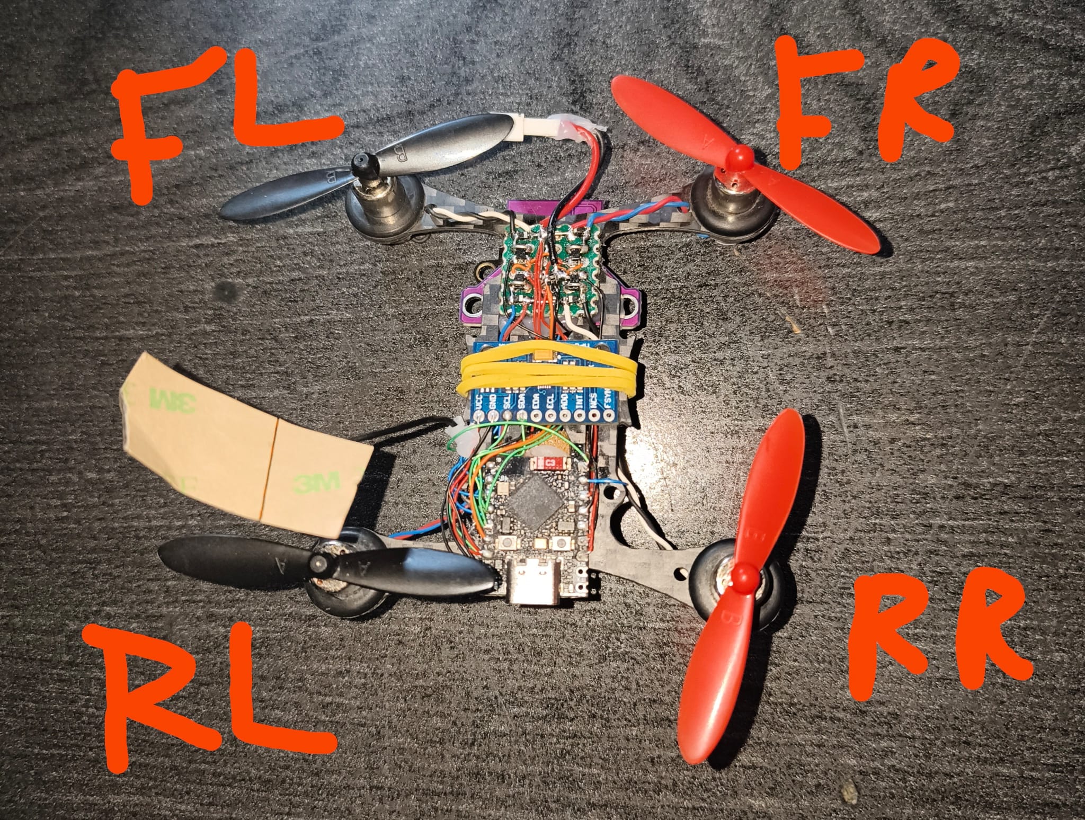
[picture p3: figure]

Figura 2 – Poziționarea motoarelor (sursa: proprie)

### Subactuarea

Un corp în spațiu are șase grade de libertate: se poate deplasa pe trei axe de translație și pe trei axe de rotație. Drona are însă doar patru comenzi independente, propulsia totală și cele trei momente, roll, pitch și yaw. Se spune că sistemul este subactuat, adică are mai puține comenzi decât grade de libertate.

Consecința este importantă pentru felul în care este organizat programul. Forța produsă de elice este întotdeauna perpendiculară pe corpul dronei, deci, stând dreaptă, drona nu poate produce nicio forță orizontală. Ca să se deplaseze în față, trebuie mai întâi să se încline în față, astfel încât o parte din forța elicelor să acționeze pe orizontală.

Din acest motiv, partea de program care se ocupă de deplasarea orizontală nu comandă direct motoarele, ci calculează un unghi de înclinare, pe care altă parte a programului îl realizează. Această organizare pe niveluri este descrisă în secțiunea 3.3.

### Pragul minim al motoarelor

Motoarele folosite sunt motoare de curent continuu cu perii. Acestea sunt comandate folosind semnale de tip PWM (Pulse Width Modulation). Un astfel de motor comandat de nu semnal PWM cu 1% factor de umplere nu se va roti și este posibil ca valoarea factorului de umplere la care motorul începe să se rotească să fie diferită de la motor la motor.


Figura 3 – Motor cu perii de tip coreless(sursa: [9])

Functia de mixare calculeza mai întâi doar contribuția de atitudine, fără propulsia totală, ca un set de valori în jurul lui zero. Aceste valori sunt cu semn: o valoare negativă inseamnă că motorul respectiv trebuie să se rotească mai puțin decât media. Comanda finală a fiecărui motor este suma dintre propulsia totală și diferența corespunzatoare din functia de mixare care poate fi o valoare negativă. Factorul de umplere este limitat la

intervalul 0% -100 % deci o valoare negativă de comandă va rezulta un factor de umplere de 0%, moment în care motorul se oprește, posibil chiar în momentul în care drona ar avea cea mai mare nevoie de corecție. Pentru a evita o astfel de situație, în program este definit un prag minim sub care motoarele nu coboară niciodată cât timp drona este armată.

#define MOTOR_IDLE_THRUST 0.06f

Această valoare reprezintă un factor de umplere de 6% minim la care toate cele patru motoare se rotesc. Această valoare a fost măsurată experimental, detaliile find prezentate în sectiunea de rezultate experimentale.

## Reglarea automată prin regulator PID

Regulatorul PID este pe departe cel mai comun algoritm de control. Majoritatea buclelor de feedback sunt controlate de acest algoritm sau de variatii ale acestuia. Este implementată în multe forme diferite, ca regulator independent sau ca un sistem ierarhic distribuit de control al proceselor. Ingineri din toată lumea utilizeaza acest algoritm în munca lor de zi cu zi.[10]

În cazul nostru, pentru ca drona să-și mentina echilibrul nu este suficient sa comandăm motoarele o singură dată. Perturbațiile, un curent de aer, o elice ușor dezechilibrată, o greutate distribuită inegal, influenteaza tipul comenzii necesare motorului. Aici intervine acest tip de regulator în buclă inschisă care masoară orientarea reală, o compară cu cea dorită și corectează comanda în funcție de diferența dintre ele.

Diferența dintre valoarea dorită și cea măsurată se numește eroare:

const float error = setpoint - measurement;

Regulatorul PID calculează comanda pe baza acestei erori, folosind trei componente: proportională, integrală și derivativă care la rândul lor utilizează 3 parametrii care influentează comportamentul componentei: Kp, Ki, respectiv Kd. În lucrarea citată în acest subcapitol se lucrează cu forma standard a acestor parametrii K, Ti și Td unde Ti și Td reprezintă constante de timp. Subcapitolele următoare și implementarea de față utilizează forma paralelă a acestor parametrii, Kp, Ki și Kd independenți, legătura fiind Ti = Kp/Ki și Td = Kd/Kp [10].

### Componenta proportională

Componenta proporțională generează o comandă direct proporțională cu eroarea curentă:

const float p_term = pid->kp * error;

Coeficientul de proporționalitate Kp stabilește cum reacționează regulatorul: la o abatere de un grad față de unghiul dorit, comanda produsă este de o mie de ori mai mare pentru un coeficient de o mie decât pentru unul unitar.

Limitarea fundamentală a componentei proporționale este că nu poate anula complet abaterea. Rezultatul este o diferență permanentă între valoarea dorită și cea măsurată, numită eroare staționară (steady-state error) [10]. Aceasta apare din cauza modului în care funcționează componenta: comanda de corecție există doar pentru că există eroare. Dacă eroarea ar fi zero, regulatorul nu ar avea ce să corecteze. În prezența unei perturbații permanente, o baterie montată ușor descentrat, un motor care se rotește mai încet decât celelalte la aceeași comandă, bucla va rămane într-un punct de echilibru în care eroarea are exact valoarea necesară pentru a genera comanda ce compensează perturbația.

Mărimea acestei erori depinde de coeficientul de proporționalitate Kp: cu cât acesta este mai mare, cu atât abaterea necesară pentru a produce aceeași comandă este mai mică. Eroarea staționară scade, prin urmare, odată cu creșterea coeficientului, dar nu se anulează niciodată, iar dincolo de o anumită valoare bucla va oscila și, în cele din urmă, va deveni instabilă.

Practic, doar cu componenta proporțională, drona ar zbura permanent ușor înclinată, iar înclinarea ar fi cu atât mai mică cu cât reglajul este mai agresiv.

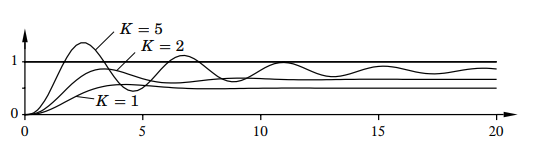
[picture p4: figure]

Figura 4 – Simularea unui sistem în buclă inchisa folosind doar componenta proportională. Functia de transfer a procesului este G(s)=(s+1)⁻³. Graficul arată valoarea dorită (setpoint) care este egală cu 1 și ieșirea buclei pentru valori diferite ale Kp. (sursa: [10])

### Componenta integrală

Componenta integrală acumulează eroarea în timp și adaugă rezultatul la comandă. Rolul ei este acela de a garanta că, în regim staționar, mărimea reglată ajunge efectiv la valoarea dorită.

Modul prin care funcționează poate fi înțeles printr-un raționament simplu. Să presupunem că sistemul ar ajunge într-un regim staționar în care eroarea rămâne constantă și diferită de zero. Componenta integrală ar continua atunci să acumuleze, iar comanda ar crește la nesfârșit, ceea ce contrazice ipoteza de regim staționar, în care comanda trebuie să fie constantă. Singura situație în care un regim staționar este posibil este, prin urmare, aceea în care eroarea este nulă. Prezența componentei integrale elimină astfel eroarea staționară descrisă anterior [10].

Din punct de vedere istoric, această componentă a purtat numele de „resetare automată": înainte de apariția ei, compensarea unei perturbații permanente se făcea prin ajustarea manuală a unei valori de bază adăugate comenzii, operație care trebuia repetată la fiecare schimbare a condițiilor de funcționare [10].

În cazul dronei, componenta integrală este cea care compensează un dezechilibru mecanic permanent: dacă centrul de greutate nu coincide cu centrul geometric, ea acumulează treptat până când diferența de turație dintre motoare anulează efectul, iar drona zboară orizontal fără ca pilotul să corecteze continuu.

Componenta integrală are însă și dezavantaje. Ea introduce o întârziere suplimentară în răspunsul buclei, reducând stabilitatea, și prezintă fenomenul de acumulare excesivă descris în secțiunea următoare.

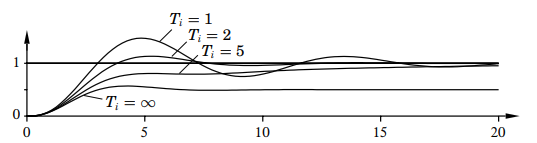
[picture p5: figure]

Figura 5 - Simularea unui sistem în buclă inchisa folosind componenta proportională și cea integrală. Functia de transfer a procesului este G(s)=(s+1)⁻³. Graficul arată valoarea dorită (setpoint) care este egală cu 1 și ieșirea buclei pentru Kp = 1 și pentru diferite valori ale Ki unde Ki = Kp/Ti. (sursa: [10])

### Componenta derivativă

Componenta derivativă este proporțională cu viteza de variație a mărimii reglate. Rolul ei este îmbunătățirea stabilității buclei.

Necesitatea ei constă în faptul că orice sistem fizic răspunde cu întârziere: între momentul în care se modifică turația motoarelor și momentul în care drona își schimbă efectiv orientarea trece un interval de timp. Un regulator care se raportează exclusiv la eroarea prezentă va continua să comande corecție și după ce mișcarea de revenire a început deja, ceea ce produce depășirea valorii dorite și, în consecință, oscilație.

Un regulator proporțional derivativ este, din acest punct de vedere, echivalent cu un regulator proporțional care nu acționează asupra erorii curente, ci asupra erorii anticipate cu Td secunde în avans, unde Td = Kd / Kp. Constanta Td reprezintă astfel orizontul de predicție [10].

Practic, dacă drona este înclinată la trei grade, dar se rotește deja rapid înapoi spre orizontală, componenta derivativă reduce corecția, pentru că mișcarea de revenire este deja în curs și o corecție suplimentară ar produce depășire în sens opus.

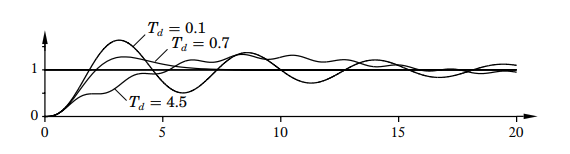
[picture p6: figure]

Figura 6 - Simularea unui sistem în buclă inchisa folosind componentele proportională, integrală și derivativă. Functia de transfer a procesului este G(s)=(s+1)⁻³. Graficul arată valoarea dorită (setpoint) care este egală cu 1 și ieșirea buclei pentru Kp = 3, Ki = 3 și diferite valori pentru Kd unde Kd = Kp x Td (sursa: [10])

Componenta derivativă ridică însă două probleme practice, ambele cu soluții consacrate. Prima apare la modificarea valorii dorite. În situația în care o comandă se modifică brusc la fel și eroarea se va modifica brusc. Rezultatul este o comandă care nu corespunde niciunei mișcări reale a procesului. Soluția uzuală este calcularea derivatei pe baza mărimii măsurate, nu a erorii. Întrucât diferența dintre cele două este tocmai derivata referinței, eliminarea acestui termen face ca regulatorul să reacționeze exclusiv la evoluția reală a procesului, nu la comenzile operatorului [10].

A doua problemă este amplificarea zgomotului. Caracteristica de frecvență a operatorului de derivare crește proporțional cu frecvența, ceea ce înseamnă că un zgomot de amplitudine mică, dar de frecvență ridicată, inerent oricărei măsurători, cu atât mai mult uneia provenite de la un senzor montat pe o structură care vibrează, produce o contribuție considerabilă în comandă. Din acest motiv componenta derivativă nu se implementează niciodată în formă pură, ci întotdeauna însoțită de o filtrare trece-jos, a cărei frecvență de tăiere stabilește un compromis între atenuarea zgomotului și întârzierea introdusă în răspuns [10].

Modul concret în care aceste două soluții au fost implementate, împreună cu valorile alese pentru fiecare buclă, este prezentat în capitolul următor.

### Saturarea și acumularea excesivă

Orice actuator are limitări. În cazul de față, viteza la care se pot roti motoarele utilizate este limitată. În cazul în care regulatorul cere mai mult decât pot motoarele livra, sistemul intră în saturație iar bucla de control se deschide: oricât ar crește comanda calculată, motoarele nu vor mai răspunde suplimentar.

Problema apare la componenta integrală. Aceasta nu are cum să știe că sistemul este saturat și continuă să adune eroarea, care nu scade. Valoarea acumulată poate crește foarte mult, iar când situația se normalizează ea trebuie mai întâi consumată, timp în care comanda rămâne la maxim deși nu mai este nevoie. Fenomenul poartă numele de integrator windup.

O soluție care previne acest fenomen constă în integrarea condiționată. Înainte de a accepta pasul de integrare, programul va calcula ce comandă ar rezulta și numai dacă eroarea curentă ar împinge comanda și mai departe în saturație aceasta nu se mai acumulează. Modul concret de implementare va fi prezentat în capitolul următor.

## Structura de reglare în cascadă

Sistemul nu folosește un singur regulator, ci mai multe, organizate pe trei niveluri. Fiecare nivel stabilește valoarea dorită pentru nivelul de sub el: nivelul exterior calculează, din altitudine și din viteza de deplasare, comanda de propulsie și unghiurile de înclinare dorite; nivelul intermediar transformă unghiul dorit în viteză unghiulară dorită; nivelul interior transformă viteza unghiulară dorită în comenzi către motoare.

Motivul acestei organizări a fost explicat în secțiunea privind subactuarea: drona nu poate comanda direct deplasarea, ci doar înclinarea.

Frecvențele de execuție diferă pentru că mărimile se schimbă cu viteze diferite. Viteza unghiulară se poate modifica foarte repede și este măsurată de giroscop la fiecare ciclu, deci bucla interioară rulează cel mai des. Unghiul se schimbă mai lent. Altitudinea și viteza de deplasare se schimbă cel mai lent și, în plus, senzorii care le măsoară furnizează date mai rar: telemetrul laser în jur de 33 de măsurători pe secundă.

În program, cele trei bucle nu rulează ca sarcini separate, ci sunt derivate dintr-un singur ciclu de 1000 Hz, prin numărare:

#define INNER_LOOP_HZ 1000

#define MID_LOOP_DIVIDER 4 // 1000 / 4 = 250 Hz

#define OUTER_LOOP_DIVIDER 20 // 1000 / 20 = 50 Hz

Avantajul este că cele trei bucle nu se pot defaza una față de alta. Dacă ar fi sarcini separate, întârzierea dintre calculul unei valori dorite și folosirea ei ar varia de la un ciclu la altul, ceea ce ar face comportamentul mai greu de analizat.

Regula uzuală pentru astfel de structuri este ca fiecare buclă interioară să ruleze de cel puțin cinci ori mai des decât cea exterioară, astfel încât, din punctul de vedere al buclei exterioare, cea interioară să pară instantanee [11]. În implementarea realizată raportul dintre nivelul exterior și cel intermediar este 5, deci respectă recomandarea; între nivelul intermediar și cel interior este 4, ușor sub valoarea recomandată. O consecință practică a acestei structuri este ordinea în care trebuie făcută reglarea: dinspre interior spre exterior. Fiecare buclă exterioară presupune că bucla de sub ea funcționează deja corect, deci nu are sens să fie reglată înaintea acesteia.

## Estimarea orientării prin fuziunea senzorilor

Pentru a corecta orientarea, sistemul trebuie mai întâi să o cunoască. Drona nu dispune de un senzor care să indice direct unghiul de înclinare, ci de un accelerometru și un giroscop, iar unghiul trebuie calculat din datele furnizate de acestea.

### Accelerometrul

Accelerometrul măsoară accelerația care acționează asupra lui. Este un dispozitiv electromecanic care detectează fie forțe statice, fie forțe dinamice de accelerație. Forțele statice includ gravitația, în timp ce forțele dinamice pot include vibrații și mișcare [12].

Această proprietate este utilă. Când drona stă nemișcată sau se deplasează uniform, singurul lucru pe care îl măsoară accelerometrul este gravitația. Dacă drona este perfect orizontală, toată accelerația apare pe axa verticală; dacă este înclinată, o parte din ea se regăsește pe celelalte axe, iar din raportul dintre componente se poate calcula unghiul [13]:

*roll_angle = (atan2(acc_y_g, acc_z_g) * (180.0 / M_PI)) – roll_offset;

*pitch_angle = (atan2(-acc_x_g, sqrt(acc_y_g * acc_y_g + acc_z_g * acc_z_g))

* (180.0 / M_PI)) – pitch_offset;

Valorile scăzute la final sunt corecții măsurate la pornire, cu drona așezată orizontal, pentru a compensa faptul că senzorul nu este montat perfect drept pe placă.

Accelerometrul are însă două probleme. Prima este că nu poate distinge între înclinare și accelerație: dacă drona accelerează lateral fără să se încline, senzorul indică practic același lucru ca în cazul unei înclinări. A doua este că vibrațiile produse de elice îl afectează puternic.

### Giroscopul

Giroscopul măsoară o altă mărime decât accelerometrul: viteza de rotație, exprimată în grade pe secundă. Nu are nicio legătură cu gravitația și nu este afectat de accelerațiile liniare.

Obținerea unghiului se face prin integrare: la fiecare ciclu, unghiul crește cu viteza măsurată înmulțită cu timpul scurs de la ciclul anterior. Aici apare însă problema fundamentală a acestui senzor, integrarea nu acumulează doar semnalul util, ci și erorile de măsurare.

Două tipuri de eroare contează, iar ele se acumulează diferit. Primul este offsetul constant: senzorul indică o valoare mică, diferită de zero, chiar și atunci când stă perfect nemișcat. Integrat, acest offset produce o eroare de unghi care crește liniar cu timpul. O abatere de doar 0,5 grade pe secundă devine, după un minut de zbor, o eroare de 30 de grade. Al doilea este zgomotul aleator, provenit din agitația termică a structurii mecanice a senzorului. Integrat, acesta produce o deplasare aleatoare a unghiului estimat, a cărei abatere crește proporțional cu rădăcina pătrată a timpului. Efectul este mai lent decât cel al offsetului, dar nu poate fi eliminat prin calibrare, fiind aleator prin natura lui [14].

La acestea se adaugă faptul că offsetul însuși nu este strict constant, ci variază lent cu temperatura și în timp, ceea ce produce tot o eroare cu creștere liniară. Contramăsura uzuală este determinarea offsetului la pornire, cu senzorul nemișcat: se măsoară valoarea indicată timp de câteva sute de eșantioane, se calculează media, iar aceasta se scade din toate citirile ulterioare. Procedura elimină componenta constantă existentă la momentul pornirii, dar nu rezolvă variația ulterioară cu temperatura și nu are niciun efect asupra zgomotului aleator [14].

Concluzia practică este că un giroscop nu poate furniza singur orientarea absolută a unei aeronave pe durata unui zbor. Oricât de bine ar fi calibrat, estimarea obținută prin integrare se îndepărtează treptat de realitate și nu se poate corecta singură, întrucât nu dispune de nicio referință externă față de care să se compare.

Astfel cele două surse sunt complementare: accelerometrul este corect pe termen lung dar zgomotos, giroscopul este precis pe termen scurt dar derivează. Modul în care sunt combinate este prezentat în capitolul 4.

## Măsurarea altitudinii și a vitezei de deplasare

### Telemetrul laser

Pentru măsurarea altitudinii este folosit un senzor ToF(Time of Flight) VL53L1X [15], orientat în jos. Acesta emite un impuls luminos infraroșu și măsoară timpul până când lumina se întoarce, reflectată de podea. Cunoscând viteza luminii, distanța rezultă direct din acest timp.

Măsurătoarea este considerată validă doar în anumite condiții, verificate în program: distanța trebuie să fie cuprinsă între 3 cm și 1,30 m, iar drona nu trebuie să fie înclinată prea mult, pentru că altfel fasciculul nu mai lovește podeaua de sub senzor, ci o zonă laterală, aflată la altă distanță.

### Senzorul de flux optic

Pentru măsurarea vitezei de deplasare pe orizontală este folosit un senzor PMW3901 [16], orientat în jos. El funcționează pe același principiu ca senzorul optic dintr-un mouse de calculator: fotografiază podeaua foarte des și compară imaginile consecutive pentru a determina cu cât s-a deplasat imaginea între ele.

Un aspect esențial este că senzorul nu măsoară o distanță, ci o deplasare unghiulară. El indică cu cât s-a mișcat imaginea în câmpul lui vizual, nu câți centimetri s-a deplasat drona. Aceeași deplasare unghiulară înseamnă câțiva centimetri dacă drona este aproape de sol și considerabil mai mult dacă este sus.

Din acest motiv, pentru a obține viteza în metri pe secundă este obligatoriu să fie cunoscută și altitudinea [17]:

const float flow_x_rad = flow->delta_x / FLOW_COUNTS_PER_RAD;

const float raw_velocity_x = (translation_x_rad / dt) * state.altitude;

Aceasta este și explicația pentru care cei doi senzori nu sunt interschimbabili și niciunul nu poate fi eliminat: fără telemetru nu există altitudine, iar fără altitudine măsurătoarea de flux optic nu poate fi convertită în viteză.

Înainte de calcularea vitezei, programul mai face o corecție. Dacă drona se înclină fără să se deplaseze, imaginea de sub ea se mișcă oricum, iar senzorul ar raporta o deplasare care nu a avut loc. Din măsurătoarea de flux se scade, de aceea, componenta datorată rotației, măsurată de giroscop.

## Execuția programului în timp real

Toate calculele descrise anterior au sens doar dacă sunt executate precis din punctul de vedere la ordini efectuării sarcinilor, priorității sarcinilor și a momentului în care se execută. Un regulator care ar trebui să ruleze la fiecare milisecundă, dar rulează uneori la două milisecunde, calculează greșit componentele integrală și derivativă, pentru că ambele depind de timpul scurs.

Pentru gestionarea acestui aspect, programul folosește sistemul de operare în timp real FreeRTOS, inclus în framework-ul ESP-IDF [18]. Acesta permite împărțirea programului în sarcini independente, fiecare cu propria prioritate, și garantează că o sarcină cu prioritate mare o întrerupe pe una cu prioritate mai mică.

Microcontrolerul ESP32-S3 dispune de două nuclee de procesare identice denumite Core 0, deseori referit ca și PRO_CPU, și Core1, deseori referit ca și APP_CPU. Aceste denumiri există cu scopul de a reflecta cum utilizează o aplicație ESP-IDF tipică cele două nuclee. Sarcinile responsabile cu utilizarea protocoalelor de comunicație precum WiFi sau Bluetooth rulează pe Core 0 iar restul sarcinilor rulează pe Core1 cu toate că o sarcină poate fi fixată pe oricare dintre cele două nuclee [18].

În implementarea realizată, bucla de control rulează pe nucleul 1, cu cea mai mare prioritate, iar comunicația cu modulul de telemetrie pe nucleul 0. Astfel, o întârziere apărută în comunicație nu poate întârzia bucla de control.

Din același motiv, în bucla de control nu se execută operații a căror durată nu poate fi garantată: fără citiri de pe rețea, fără așteptare după alte sarcini.

Atunci când două sarcini aflate pe nuclee diferite folosesc aceleași date, de exemplu comenzile primite de la pilot, scrise de sarcina de comunicație și citite de bucla de control, accesul este protejat, astfel încât bucla de control să nu poată citi jumătate din comanda veche și jumătate din cea nouă.

## Mediul de dezvoltare și bibliotecile utilizate

Firmware-ul ambelor plăci este dezvoltat folosind ESP-IDF (Espressif IoT Development Framework), mediul oficial de dezvoltare pus la dispoziție de Espressif pentru microcontrolerele din familia ESP32. Acesta oferă un lanț de instrumente, API-uri, componente și fluxuri de lucru pentru dezvoltarea de aplicații pentru ESP32-S3 utilizând sistemele de operare Windows, Linux și macOS [19].

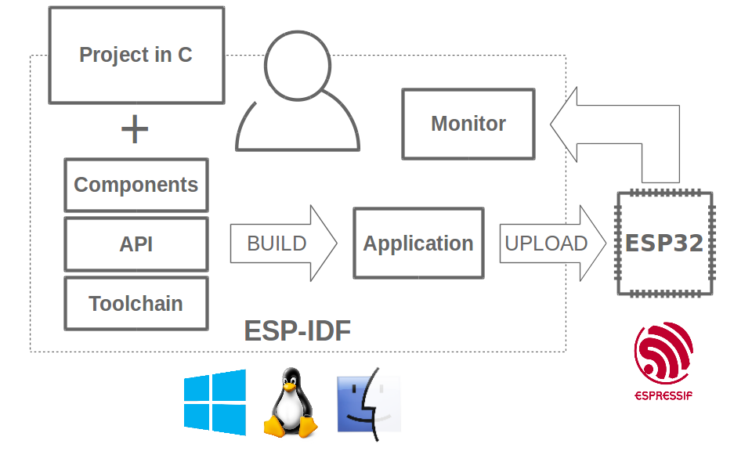
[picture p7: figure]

Figura 7 – Funcționarea mediul de lucru ESP-IDF (sursa: [19])

Un proiect ce utilizează acest mediu de dezvoltare este organizat în componente. O componentă este un director care conține codul sursă, fișierele antet publice și un fișier de configurare în care se declară de ce alte componente depinde. Compilarea este gestionată prin CMake, iar sistemul determină automat ordinea de compilare pe baza dependențelor declarate.

Această organizare a fost utilă pentru proiect: fiecare funcție majoră a devenit o componentă separată, driverul senzorului inerțial, estimatorul de orientare, estimatorul de navigație, regulatorul PID, bucla de control, driverul de motoare, monitorizarea acumulatorului, cu limite clare între ele. O componentă poate folosi altă componentă doar dacă a declarat explicit dependența, ceea ce împiedică apariția legăturilor accidentale între părți care ar trebui să rămână independente.

Pe lângă componentele scrise în cadrul proiectului au fost folosite și biblioteci externe. Pentru telemetrul laser este utilizat driverul oficial pus la dispoziție de producător, integrat printr-un strat de adaptare scris în cadrul proiectului, care implementează funcțiile de comunicație pe magistrala I2C. Pentru senzorul de flux optic, secvența de inițializare a registrelor este preluată din driverul cu sursă deschisă publicat de Bitcraze, cu atribuirea și licența păstrate în codul sursă. Modulul de cameră folosește driverul esp32-camera, pus la dispoziție de Espressif. La acestea se adaugă driverele incluse în ESP-IDF pentru perifericele microcontrolerului: magistralele I2C și SPI, interfața serială, generatorul de PWM folosit pentru comanda motoarelor și convertorul analog-digital.

Cele două plăci constituie două proiecte ESP-IDF separate, care partajează o singură componentă comună, cea care definește structura mesajelor schimbate între ele.

Componenta este inclusă în ambele proiecte, astfel încât o modificare a formatului mesajelor se aplică automat de ambele părți și nu pot apărea nepotriviri între ceea ce trimite o placă și ceea ce așteaptă cealaltă.

# Elaborarea proiectului

Capitolul anterior a prezentat noțiunile teoretice pe care se sprijină sistemul. Capitolul de față descrie modul în care acestea au fost transpuse într-un program care rulează pe hardware real: ce s-a cerut de la sistem, cum a fost împărțit, ce decizii de proiectare au fost luate și pe ce argumente, cum arată implementarea și cum a fost verificată.

Pentru fiecare valoare numerică aleasă se indică motivul care a dus la ea. Acolo unde o valoare nu a fost determinată experimental, ci estimată, acest lucru este spus explicit: o parte dintre parametrii sistemului sunt încă valori de plecare, iar prezentarea lor ca fiind altceva ar face lucrarea mai puțin utilă, nu mai convingătoare. Referințele către codul sursă indică fișierul și linia, astfel încât fiecare afirmație să poată fi verificată direct.

## Specificația sistemului

Specificația a fost formulată înaintea implementării și a rămas neschimbată pe parcursul proiectului. Este împărțită în cerințe funcționale, adică ce trebuie să facă sistemul, cerințe nefuncționale, adică în ce condiții trebuie să o facă, și constrângeri impuse de hardware-ul ales.

### Cerințe funcționale

Sistemul trebuie să îndeplinească următoarele funcții:

• să stabilizeze automat orientarea aeronavei, astfel încât pilotul să comande o înclinare dorită, nu turația fiecărui motor în parte;

• să permită menținerea automată a altitudinii și a poziției pe orizontală, folosind exclusiv senzorii aflați la bord, fără nicio referință externă de tip GPS;

• să poată fi comandat fără telecomandă dedicată, de pe un dispozitiv pe care pilotul îl are deja;

• să captureze imagini pe un card de memorie, în condiții de iluminare constantă între cadrele aceleiași sesiuni;

• să permită modificarea coeficienților de reglare în timpul funcționării, fără reprogramarea plăcii;

• să înregistreze datele de zbor într-o formă care permite analiza ulterioară a comportamentului.

### Cerințe nefuncționale

Cea mai restrictivă cerință a sistemului este de natură temporală. Bucla interioară de reglare trebuie să ruleze la 1000 Hz, deci are un termen limită de o milisecundă pe iterație. În acest interval trebuie să încapă citirea unității inerțiale pe magistrala I2C, actualizarea estimatorului de orientare, cele trei regulatoare de viteză unghiulară, operația de mixare și scrierea celor patru canale PWM.

Din această cerință derivă o regulă de proiectare care se regăsește în întregul cod și care este formulată explicit în antetul fișierului principal al controlerului:

„Partea de 1 kHz nu așteaptă niciodată. Fiecare citire între sarcini din fc_task folosește un timeout ZERO și continuă cu copia anterioară în caz de eșec. Date vechi cu un ciclu sunt întotdeauna preferabile unui termen limită ratat de 1 ms."

flight_controller/main/main.c, liniile 15–18

A doua cerință nefuncțională este de siguranță și poate fi enunțată într-o singură propoziție: nicio cale de execuție care nu autorizează explicit motoarele nu are voie să le lase în mișcare. Modul în care este garantată această proprietate este descris în secțiunea 4.4.6.

A treia cerință privește observabilitatea. Un sistem de reglare în care nu se poate vedea ce fac buclele nu poate fi reglat altfel decât prin încercări repetate, iar o încercare nereușită înseamnă, în cazul unei drone, o coliziune. Sistemul trebuie deci să expună în exterior nu doar rezultatul reglării, ci și starea internă a fiecărei bucle.

### Constrângeri impuse de hardware

Alegerile de hardware, prezentate în subcapitolul 1.3, au consecințe directe asupra structurii programului. Ele nu sunt detalii de implementare, ci constrângeri de proiectare:

Constrângere | Consecință asupra proiectării
Motoare de curent continuu cu perii, comandate prin tranzistoare | Comanda este un factor de umplere PWM, nu un protocol digital de tip DShot. Nu există confirmare de la motor și nu există măsurare a turației.
Absența unui magnetometru | Direcția absolută nu este observabilă. Girația nu poate avea buclă de unghi, ci doar de viteză unghiulară.
Absența unui receptor GPS | Poziția pe orizontală se estimează exclusiv din flux optic și altitudine, ambele valabile doar aproape de sol.
O singură magistrală I2C, partajată între unitatea inerțială și telemetrul laser | Ordinea de inițializare devine o constrângere de corectitudine, nu o preferință (secțiunea 4.4.9).
Card SD cu timp de scriere nedeterminist | Capturarea imaginilor nu poate rula pe aceeași cale de execuție cu comanda aeronavei.
Alimentare de la un acumulator 1S de mică capacitate | Puterea de emisie radio și numărul de sarcini active devin decizii cu impact asupra autonomiei.

Tabelul 1 – Constrângerile hardware și consecințele lor asupra structurii programului

### Delimitarea funcționalităților

Pentru claritate, este util de precizat și ce nu face sistemul. Nu există planificare autonomă de traiectorie: drona execută comenzile pilotului, iar modurile automate se limitează la menținerea altitudinii și a poziției curente. Nu există evitarea obstacolelor. Nu se realizează nicio prelucrare a imaginilor la bord, iar reconstrucția tridimensională propriu-zisă nu face obiectul acestei lucrări; sistemul produce setul de imagini, nu scena reconstruită din el.

## Arhitectura sistemului

### Împărțirea pe două plăci

Decizia arhitecturală centrală, anunțată în subcapitolul 1.3, este separarea sistemului pe două microcontrolere distincte, în locul unuia singur.

Motivul este izolarea temporală. Bucla de control are un termen limită de o milisecundă. Scrierea unei fotografii pe un card SD poate bloca sute de milisecunde atunci când cardul își execută operațiile interne de nivelare a uzurii, iar durata acestei blocări nu poate fi nici prezisă, nici limitată de program. Pe un singur microcontroler, cele două activități ar concura pentru aceleași resurse; separate pe plăci diferite, nicio întârziere din partea de imagini nu poate ajunge la bucla de control, indiferent cât durează.

Aceeași observație apare formulată în documentația componentei de capturare:

„O scriere FAT pe un card SD ieftin poate bloca sute de milisecunde. În interiorul /api/capture asta ar bloca serverul HTTP, ceea ce ar bloca cererile de intrare la 20 Hz ale tabloului de bord, ceea ce ar declanșa watchdog-ul de browser în plin zbor."

telemetry_module/components/camera_sd/README.md

Argumentul este general: separarea nu este motivată de puterea de calcul insuficientă a unui singur microcontroler, ci de imposibilitatea de a garanta termene limită atunci când pe același procesor rulează activități cu durată nemărginită. Un al doilea microcontroler de mici dimensiuni costă mai puțin decât efortul de a face determinist accesul la un card SD.

Prețul plătit pentru această separare este o legătură serială între plăci, care trebuie proiectată, implementată și verificată. Ea face obiectul subcapitolului 4.3.

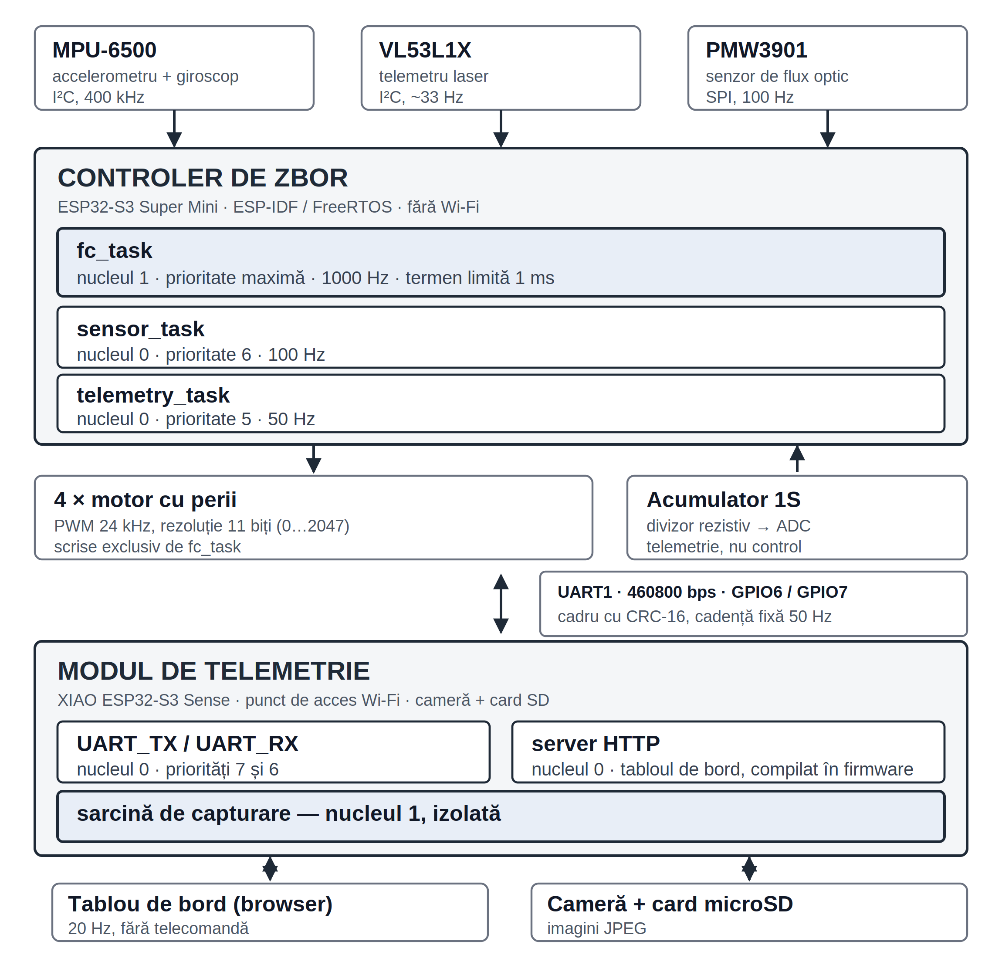
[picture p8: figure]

Figura 8 – Arhitectura sistemului pe două plăci, cu sarcinile, nucleele și legăturile dintre ele

### Organizarea pe componente

Fiecare funcție majoră a firmware-ului este o componentă ESP-IDF separată, cu limite explicite. Organizarea nu este decorativă: sistemul de compilare impune ca o componentă să poată folosi altă componentă doar dacă a declarat explicit dependența, ceea ce împiedică apariția legăturilor accidentale între părți care ar trebui să rămână independente. Controlerul de zbor este format din opt componente proprii și două drivere externe:

Componentă | Rol
imu_driver | Comunicația I2C cu unitatea inerțială, conversia datelor brute în unități fizice, calibrarea la pornire
attitude_estimator | Filtrul complementar: din accelerație și viteze unghiulare rezultă unghiurile de orientare
nav_estimator | Din distanță și flux optic rezultă altitudinea și viteza de deplasare pe orizontală
pid_controller | Legea de reglare propriu-zisă, fără nicio stare globală
pid_registry | Tabelul de coeficienți, coada de depanare și generatorul de semnal de test
flight_control | Cascada de reglare, mașina de stări de armare, mixerul
motor_driver | Cele patru canale PWM și conversia din propulsie normalizată în factor de umplere
battery_monitor | Tensiunea acumulatorului, măsurată printr-un divizor rezistiv și convertorul analog-digital
vl53l1x_driver | Driverul oficial al producătorului, plus stratul de adaptare I2C scris în cadrul proiectului
pmw3901_driver | Driver propriu, cu secvența de inițializare a registrelor preluată de la Bitcraze

Tabelul 2 – Componentele firmware-ului de pe controlerul de zbor

Separarea are un efect concret asupra implementării regulatorului. Componenta pid_controller nu conține nicio stare globală, iar acest lucru este afirmat explicit în cod:

„Nicio stare nu există în acest fișier. Fiecare instanță este complet conținută în structura apelantului, deci nu există nimic de blocat și nimic partajat între cele opt instanțe."

flight_controller/components/pid_controller/pid_controller.c, liniile 18–19

Aceasta este proprietatea care permite ca aceeași implementare să fie instanțiată de opt ori, cu parametri complet diferiți, fără niciun mecanism de sincronizare între instanțe și fără riscul ca o buclă să influențeze accidental starea alteia.

Modulul de telemetrie este organizat după același principiu, cu șase componente proprii: control_state pentru sinteza comenzilor, uart_link pentru legătura serială, wifi_ap pentru punctul de acces, http_server pentru tabloul de bord, gs_link pentru puntea către stația de sol și camera_sd pentru capturarea imaginilor.

### Repartizarea sarcinilor pe nuclee și priorități

Ambele microcontrolere au două nuclee de procesare, iar sistemul de operare în timp real permite fixarea fiecărei sarcini pe un nucleu anume, prin funcția xTaskCreatePinnedToCore() [20]. Repartizarea aleasă este următoarea:

Placă | Sarcină | Nucleu | Prioritate | Cadență | Fișier și linie
Controler | fc_task | 1 | maximă | 1000 Hz | main.c:542
Controler | sensor_task | 0 | 6 | 100 Hz | sensor_task.c:45
Controler | telemetry_task | 0 | 5 | 50 Hz | main.c:576
Telemetrie | UART_TX | 0 | 7 | 50 Hz | uart_link.c:50
Telemetrie | UART_RX | 0 | 6 | continuu | uart_link.c:51
Telemetrie | gs_link | 0 | 4 | la cerere | gs_link.c:41
Telemetrie | capturare imagini | 1 | normală | la cerere | main.c, CORE_CAMERA

Tabelul 3 – Repartizarea sarcinilor pe nuclee, priorități și cadențe

Justificarea priorităților. Ordinea urmează principiul atribuirii pe baza perioadei, prezentat în secțiunea 3.6: sarcina cu perioada cea mai scurtă primește prioritatea cea mai mare. Bucla de control are perioada de 1 ms și primește prioritatea maximă disponibilă; sarcina de senzori are 10 ms și prioritatea 6; sarcina de telemetrie are 20 ms și prioritatea 5. Este exact ordonarea recomandată de teoria planificării în timp real pentru sarcini periodice independente.

Pe modulul de telemetrie, sarcina de transmisie este plasată deasupra celei de recepție dintr-un motiv concret: ratarea unui slot de transmisie riscă să declanșeze watchdog-ul de 300 ms al controlerului și să dezarmeze drona în zbor, în timp ce un cadru de stare recepționat cu întârziere face doar tabloul de bord ușor învechit. Cele două consecințe nu sunt comparabile ca gravitate, deci nici prioritățile nu trebuie să fie egale.

Justificarea fixării pe nuclee. Pe controlerul de zbor nu rulează Wi-Fi. Separarea nucleelor nu este motivată aici de traficul radio, ci de izolarea buclei de control față de sarcinile proprii ale aplicației care execută operații de intrare-ieșire cu durată nedeterministă: sarcina de senzori face citiri I2C care pot dura milisecunde, iar cea de telemetrie scrie pe interfața serială. Ambele stau pe nucleul 0, iar bucla de control are nucleul 1 pentru ea singură.

Pe modulul de telemetrie situația este cea uzuală pentru o aplicație ESP-IDF: Wi-Fi și stiva de rețea rulează oricum pe nucleul 0, împreună cu serverul HTTP și cele două sarcini seriale, astfel încât întreaga cale de comandă este planificată de un singur planificator, fără latență între nuclee. Sarcina de capturare a imaginilor este singura de pe nucleul 1, tocmai pentru că este singura care blochează pentru perioade lungi și impredictibile.

### Schimbul de date între sarcini

Sarcinile nu comunică prin apeluri directe, ci prin structuri partajate, protejate diferit în funcție de natura datelor. Trei mecanisme sunt folosite, iar alegerea fiecăruia are o motivație distinctă.

Spinlock pentru comanda pilotului. Comanda primită de la modulul de telemetrie este scrisă de o sarcină de pe nucleul 0 și citită de bucla de control de pe nucleul 1. Copierea structurii nu este atomică, deci fără protecție bucla ar putea citi jumătate din comanda veche și jumătate din cea nouă. Secțiunea critică este foarte scurtă, doar o copiere de structură, ceea ce justifică folosirea unui spinlock în locul unui mutex:

taskENTER_CRITICAL(&control_input_spinlock);

control = control_input;

input_age_us = now_us - last_control_input_us;

taskEXIT_CRITICAL(&control_input_spinlock);

flight_control.c:832–835

Mutex asimetric pentru starea de navigație. Sarcina de senzori publică rezultatul la 100 Hz, iar bucla de control îl consumă la 1000 Hz. Cele două capete folosesc timeout-uri diferite, iar asimetria este chiar proiectarea: scriitorul acceptă să aștepte până la 2 ms din bugetul lui de 10 ms și renunță la o publicare dacă mutexul este ocupat, în timp ce cititorul folosește timeout zero și păstrează copia din iterația anterioară. Partea de 1 kHz nu așteaptă niciodată, iar o valoare veche cu o milisecundă este complet inofensivă pentru o mărime care se actualizează oricum de zece ori mai rar.

Semafor pentru ordinea de pornire. Un semafor binar sincronizează un eveniment care se produce o singură dată: momentul în care magistrala I2C a fost creată și senzorii de navigație pot fi porniți fără să concureze pentru ea. Detaliile sunt în secțiunea 4.4.9.

## Protocolul de comunicație între plăci

### Formatul cadrului

Legătura dintre cele două plăci este serială asincronă, la 460800 biți pe secundă, pe interfața UART1, cu transmisia pe GPIO6 și recepția pe GPIO7 (main.c:526–531). Viteza a fost aleasă suficient de mare încât un cadru complet să ocupe o fracțiune neglijabilă din perioada de 20 ms: la 460800 bps, un cadru de 69 de octeți se transmite în aproximativ 1,5 ms.

Structura unui cadru este prezentată în figura următoare.

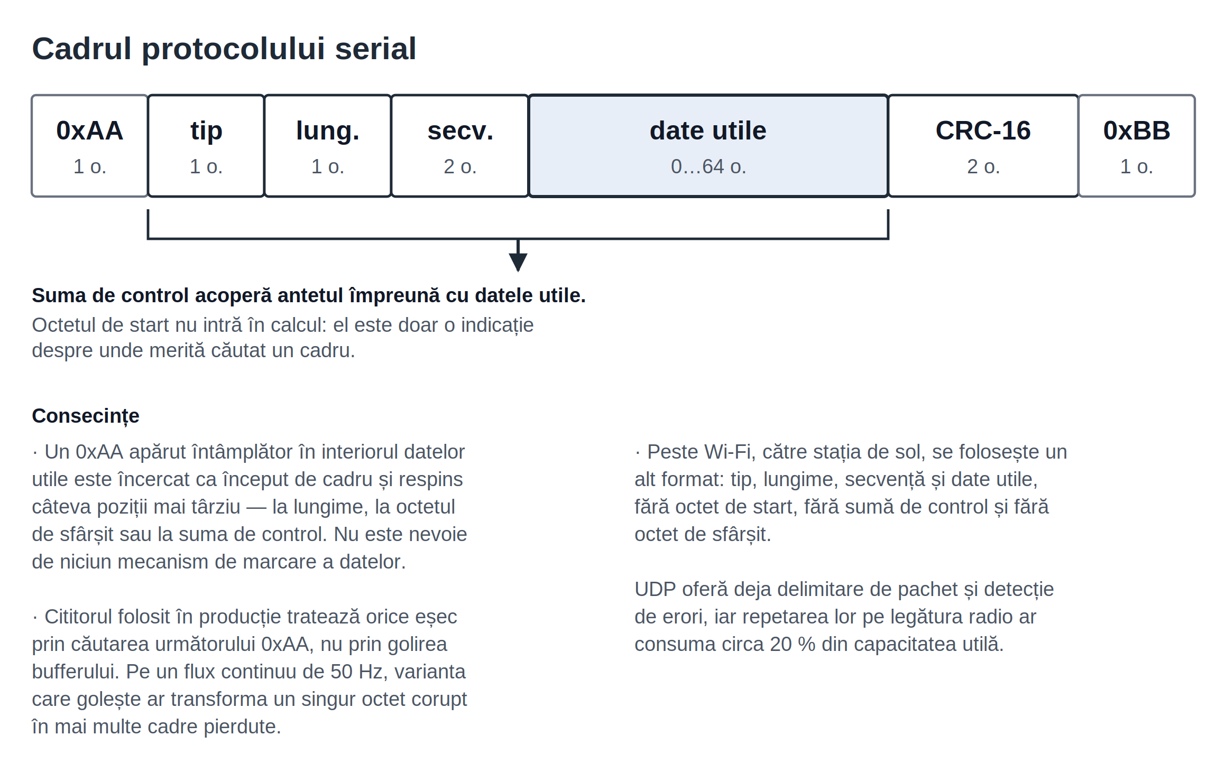
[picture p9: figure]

Figura 9 – Formatul cadrului pe legătura serială și consecințele alegerilor făcute

Cei opt octeți de încadrare sunt necesari pentru că o linie serială nu oferă nici delimitare de cadru, nici detecție de erori. Este util de comparat cu legătura peste Wi-Fi descrisă în secțiunea 4.5.5, unde exact din motivul opus se folosește un format mai simplu: UDP oferă deja ambele proprietăți, deci repetarea lor ar fi o risipă.

Alegerea codului de detecție a erorilor. Se folosește CRC-16/CCITT-FALSE, cu polinomul generator 0x1021 și valoarea inițială 0xFFFF, calculat bit cu bit (telemetry_uart.c:44–58). Este un algoritm standardizat și larg folosit în protocoale seriale [21]. Implementarea bit cu bit a fost preferată celei bazate pe tabel de căutare pentru un motiv măsurabil, notat direct în cod:

„Un tabel ar fi de aproximativ opt ori mai rapid, dar costă 512 octeți de .rodata; la 50 Hz, pe un cadru de cel mult 69 de octeți, diferența nu contează."

shared_components/telemetry_uart/telemetry_uart.c, liniile 41–43

Ce acoperă suma de control. CRC-ul se calculează peste antet și date utile împreună, nu doar peste datele utile. Consecința este că octetul de start 0xAA nu decide validitatea unui cadru; el este doar o indicație despre unde merită căutat. Un octet 0xAA care apare din întâmplare în interiorul datelor utile va fi încercat ca început de cadru și respins câteva poziții mai târziu, la verificarea lungimii, a octetului de sfârșit sau a sumei de control. Tocmai de aceea nu există niciun mecanism de marcare a datelor: suma de control este cea care decide, iar un mecanism suplimentar ar adăuga complexitate fără să adauge siguranță (telemetry_uart.c:177–180).

### Tipurile de mesaje

Protocolul definește unsprezece tipuri de mesaje (telemetry_uart.h:35–51), grupate pe direcții. Notațiile din tabel sunt: CZ pentru controlerul de zbor, MT pentru modulul de telemetrie și SS pentru stația de sol.

Cod | Mesaj | Direcție | Rol
1 | IMU | CZ → MT | Date brute inerțiale, pentru diagnosticarea vibrațiilor și a montajului
2 | BATTERY | CZ → MT | Tensiunea acumulatorului
3 | STATUS | CZ → MT | Cadrul afișat de tabloul de bord, trimis la 50 Hz
10 | CONTROL | MT → CZ | Comenzile pilotului: propulsie, unghiuri dorite, viteză de girație, indicatori
11 | ARMING | MT → CZ | Cerere de armare sau oprire de urgență
12 | MODE | MT → CZ | Modul de zbor: manual, menținere altitudine, menținere poziție
13 | GAINS | MT → CZ | Coeficienți de reglare modificați de la tabloul de bord
20 | PID_DEBUG | CZ → SS | Interiorul unei bucle, la cadență ridicată
21 | PID_GAINS | ambele | Coeficienți, pentru stația de sol
22 | PID_SELECT | SS → CZ | Selectarea buclei ale cărei date interne sunt transmise
23 | PID_INJECT | SS → CZ | Parametrii semnalului de test injectat în valoarea dorită

Tabelul 4 – Tipurile de mesaje definite de protocol

### Cadență fixă de transmisie

Cadrul de comandă pleacă de cincizeci de ori pe secundă indiferent dacă pilotul atinge sau nu ceva. Aceasta este o decizie de proiectare, nu o simplificare.

O implementare care ar trimite doar la schimbarea comenzii ar părea mai eficientă și ar dezarma drona în momentul în care pilotul încetează să apese butoane. Motivul este că receptorul nu poate distinge „nu am nimic de spus" de „legătura a murit": ambele arată identic pe fir. Tăcerea este semnalul de defect, deci emisia trebuie să fie continuă pentru ca tăcerea să însemne ceva. Mecanismul care interpretează această tăcere face obiectul secțiunii următoare.

### Supravegherea legăturii de comandă

Pierderea legăturii cu pilotul nu este un caz excepțional, ci o situație care apare în mod curent: o întrerupere scurtă a semnalului radio, un telefon care își blochează ecranul, o filă de browser trecută în fundal. Diferența dintre aceste situații nu este vizibilă din interiorul programului — toate arată identic, ca o absență de date — dar consecințele lor sunt diferite, iar sistemul trebuie să reacționeze diferit la fiecare.

Mecanismul este organizat pe două niveluri, câte unul pe fiecare placă, pentru că fiecare nivel acoperă un mod de defectare pe care celălalt nu îl poate observa.

Nivelul întâi: legătura serială, supravegheată de controlerul de zbor.

#define LINK_TIMEOUT_US 300000

flight_control.c:69

La fiecare iterație de 1 kHz se calculează vechimea ultimei comenzi primite, iar dacă aceasta depășește fereastra, legătura este declarată pierdută:

link_ok = (last_control_input_us != 0) && (input_age_us < LINK_TIMEOUT_US);

flight_control.c:838

Prima condiție tratează un caz ușor de omis: valoarea zero înseamnă că nu a sosit niciodată nimic de la pornire, ceea ce nu este același lucru cu o legătură funcțională.

Justificarea valorii de 300 ms rezultă direct din cadența de transmisie. La 50 Hz, adică un cadru la fiecare 20 de milisecunde, fereastra tolerează cincisprezece cadre pierdute consecutiv. Este suficient de lungă pentru a trece peste o întrerupere scurtă a legăturii radio, fără ca drona să se dezarmeze la fiecare perturbație, și suficient de scurtă pentru a conta: o aeronavă care continuă să execute ultima comandă primită timp de o secundă într-un spațiu închis este periculoasă.

Nivelul al doilea: browserul, supravegheat de modulul de telemetrie.

#define INPUT_TIMEOUT_US 500000 // 500 ms

#define DISARM_TIMEOUT_US 3000000 // 3 s

control_state.c:131–132

Acest nivel există pentru un mod de defectare pe care primul nu îl poate detecta. Dacă browserul pilotului se închide sau telefonul se blochează, modulul de telemetrie continuă să transmită cadre perfect valide, la cadență nominală, cu ultimele comenzi cunoscute. Din punctul de vedere al controlerului de zbor, legătura este în perfectă stare, iar watchdogul de 300 de milisecunde nu se declanșează niciodată. Drona ar rămâne armată, în aer, executând la nesfârșit ultima comandă primită, fără ca nimeni să o mai piloteze.

Cele două praguri corespund unor ipoteze diferite despre ce s-a întâmplat:

Prag | Ipoteza | Acțiunea
500 ms | Pilotul și-a pierdut momentan atenția, sau legătura a avut o întrerupere scurtă | Se eliberează toate comenzile direcționale; trimul de propulsie se păstrează
3 s | Browserul nu se mai întoarce | Se retrage cererea de armare, pe care controlerul o tratează imediat

Tabelul 5 – Cele două praguri ale watchdogului de browser și reacția fiecăruia

Distincția contează. La 500 de milisecunde, drona se oprește din manevră și se nivelează, dar nu își pierde propulsia — rămâne la altitudinea la care era, în loc să cadă. Aceasta este reacția potrivită pentru o întrerupere trecătoare. La 3 secunde, ipoteza se schimbă: un browser absent de atât timp nu se mai întoarce la timp ca să mai conteze, iar o aeronavă armată și nesupravegheată nu este acceptabilă.

Consecința asupra repornirii. Indiferent de nivelul care s-a declanșat, revenirea legăturii nu repornește motoarele. Pierderea legăturii duce sistemul în starea DISARMED, iar ieșirea din această stare se face exclusiv prin poarta de armare descrisă în secțiunea 4.4.6, cu toate cele patru condiții ale ei. În particular, propulsia comandată trebuie să fie din nou sub 0,02, ceea ce înseamnă că o legătură restabilită în timp ce pilotul ține apăsat butonul de urcare nu va rearma drona. Este exact comportamentul dorit: repornirea trebuie să fie o decizie explicită a pilotului, nu o consecință automată a restabilirii unui semnal.

Observabilitatea din exterior. Starea watchdogului este transmisă la 50 Hz către tabloul de bord, prin indicatorul LINK_OK din cadrul de stare (telemetry_uart.h:68). Fără el, pilotul nu ar avea nicio modalitate de a distinge o dronă care nu răspunde pentru că legătura s-a pierdut de una care nu răspunde din alt motiv — două situații care cer reacții complet diferite.

Ce nu acoperă acest mecanism. Cele trei temporizări supraveghează legătura de comandă, nu execuția programului. Ele detectează absența datelor, nu blocarea unei sarcini. Dacă bucla de control s-ar bloca într-o operație care nu se termină, watchdogurile descrise aici nu ar observa nimic, pentru că ele sunt evaluate chiar de codul care s-ar fi blocat. Protecția împotriva acestei situații ar reveni watchdogului hardware al microcontrolerului, care în implementarea de față rămâne la configurația implicită a mediului de dezvoltare și nu a fost configurat explicit în cadrul proiectului.

### Tratarea erorilor de recepție

Există două funcții de citire a unui cadru. Prima presupune că următorul octet din flux este începutul unui cadru și golește bufferul la orice eroare. A doua, folosită în producție, tratează fiecare eșec printr-o reluare: caută următorul octet 0xAA și încearcă din nou de acolo.

Diferența contează pe un flux continuu. Varianta care golește bufferul aruncă și cadrele bune deja aflate în coadă în spatele octetului corupt, transformând o singură eroare de transmisie în mai multe cadre pierdute. Pe traficul de tip cerere-răspuns strategia ar fi acceptabilă, dar pe un flux de 50 Hz este exact comportamentul de evitat (telemetry_uart.c:172–176).

## Controlerul de zbor

### Implementarea regulatorului PID

Componenta pid_controller implementează cele trei soluții descrise teoretic în secțiunea 3.2. O iterație completă este o singură funcție, pid_update() (pid_controller.c:80–146).

Ordinea operațiilor nu este arbitrară. Componentele proporțională și derivativă se calculează înaintea celei integrale, pentru că testul anti-windup are nevoie de ieșirea completă candidat: trebuie să știe cât ar fi suma finală înainte de a decide dacă acest pas de integrare ar împinge sistemul și mai adânc în saturație.

Derivata calculată pe mărimea măsurată. Este soluția pentru problema modificării bruște a valorii dorite, descrisă în secțiunea 3.2.3:

d_raw = -(measurement - pid->prev_measurement) / dt;

pid_controller.c:99

Semnul minus este tot ce rămâne după eliminarea derivatei referinței: derivata erorii este diferența dintre derivata referinței și derivata măsurii, iar prima este exact termenul aruncat intenționat.

Filtrarea derivatei. Se folosește un filtru trece-jos de ordinul întâi, cu coeficientul calculat o singură dată la inițializare, din frecvența de tăiere cerută și din perioada nominală a buclei:

const float rc = 1.0f / (2.0f * (float)M_PI * d_cutoff_hz);

pid->d_alpha = nominal_dt / (rc + nominal_dt);

pid_controller.c:70–71

Frecvențele de tăiere diferă de la un nivel la altul, pentru că zgomotul prezent la intrare diferă:

Buclă | Frecvență de tăiere | Motivul alegerii
Viteză unghiulară | 60 Hz | Primește giroscopul brut, deci are nevoie de cea mai puternică filtrare
Unghi | 30 Hz | Intrarea este deja netezită de estimatorul de orientare
Viteză și altitudine | 10 Hz | Mărimile se schimbă lent, iar filtrarea agresivă nu introduce întârziere semnificativă la 50 Hz

Tabelul 6 – Frecvențele de tăiere ale filtrului derivatei (flight_control.c:177–179)

Integrarea condiționată. Este implementarea exactă a mecanismului descris în secțiunea 3.2.4:

const float candidate_integrator = pid->integrator + (pid->ki * error * dt);

const float candidate_output = p_term + candidate_integrator + d_term;

bool freeze_integrator = false;

if (candidate_output > pid->out_max && error > 0.0f) {

freeze_integrator = true;

} else if (candidate_output < pid->out_min && error < 0.0f) {

freeze_integrator = true;

}

pid_controller.c:109–118

Se observă condiția dublă: nu este suficient ca ieșirea candidat să depășească limita, ci trebuie ca și eroarea să ceară mai mult în aceeași direcție. O eroare care ar scoate bucla din saturație este integrată normal. Mecanismul corespunde soluției de integrare condiționată descrise de Åström și Hägglund [10].

Două tipuri de resetare, folosite în situații diferite. Funcția pid_reset() șterge integratorul și istoricul derivatei, dar păstrează coeficienții; este calea folosită la armare și la dezarmare. Funcția pid_set_gains() schimbă coeficienții și păstrează integratorul; este calea folosită la reglarea în timpul zborului. Dacă a doua ar șterge integratorul, fiecare mișcare a unui cursor pe tabloul de bord ar produce o smucitură a dronei, ceea ce ar face reglarea în zbor imposibilă.

Câmpurile de telemetrie. Fiecare iterație înregistrează dacă ieșirea a fost limitată și dacă integratorul a fost oprit sau plafonat (pid_controller.c:142–143). Motivul este dat explicit în cod:

„Înregistrarea celor două condiții de saturație aici este singurul loc în care sunt observabile — ambele sunt calculate mai sus și altfel ar fi aruncate, iar «de ce nu răspunde bucla asta» este aproape întotdeauna una dintre ele."

flight_controller/components/pid_controller/pid_controller.c, liniile 136–138

### Structura în cascadă și cele opt bucle

Cascada descrisă teoretic în secțiunea 3.3 este instanțiată ca opt regulatoare independente, configurate la inițializare (flight_control.c:315–370). Structura completă, cu mărimile care circulă între niveluri, este prezentată în figura următoare.

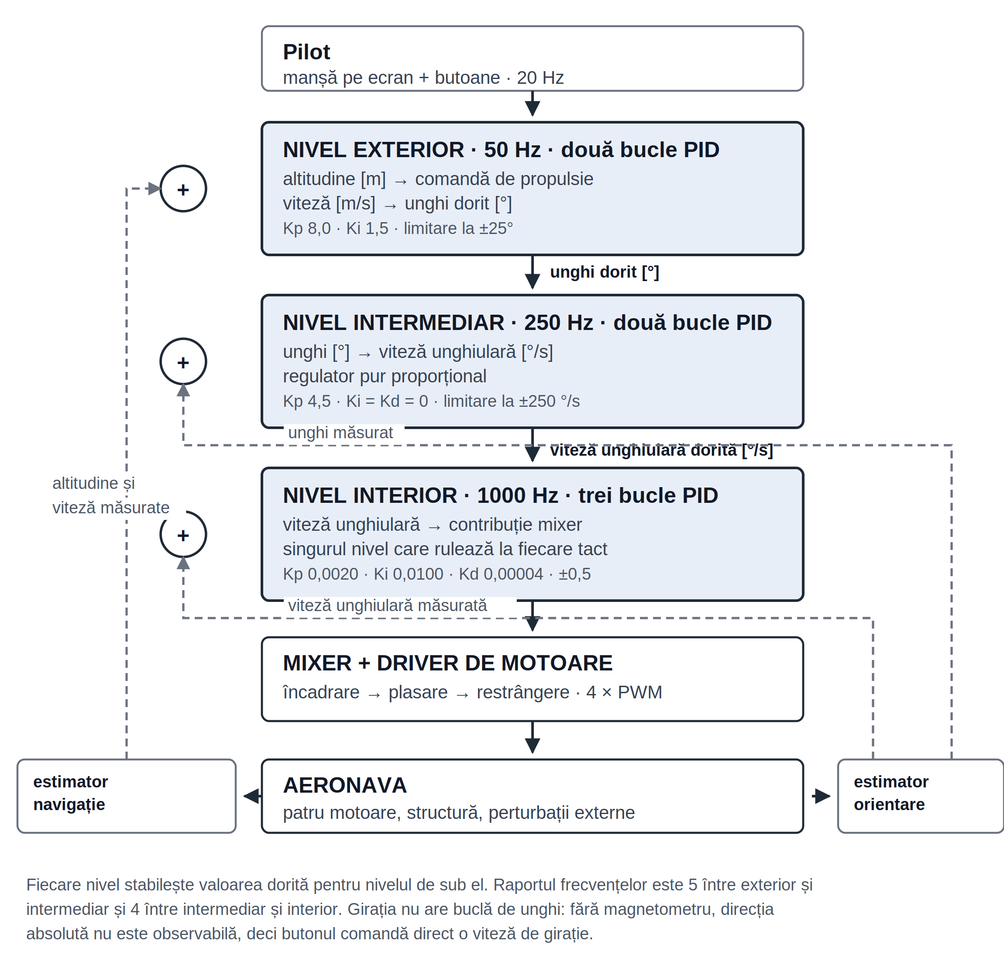
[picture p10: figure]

Figura 10 – Structura de reglare în cascadă, cu mărimile schimbate între niveluri

Cele opt bucle și limitele lor:
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

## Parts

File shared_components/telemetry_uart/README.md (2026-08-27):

# `telemetry_uart` — the two-board wire protocol

The framed binary UART protocol spoken between the **flight controller** board and the
**telemetry module** board, plus the framing/CRC code that implements it. This is the only
component in the repo that is shared: it lives once on disk here and is pulled into *both*
firmware projects through `EXTRA_COMPONENT_DIRS` in each project's top-level `CMakeLists.txt`.
It is **not vendored** — there is no second copy to keep in sync, which also means any edit here
changes both firmwares at once.

```
flight_controller  <──── UART ────>  telemetry_module  <──── UDP ────>  tools/ground_station
   (this protocol)                     (this protocol)                    (same frames, tunnelled)
```

## What it does

1. Defines the **frame format** — start byte, message type, payload length, sequence number,
   payload, CRC16, end byte.
2. Defines the **message types** and the **payload structs** for each one. These structs are the
   actual contract: both boards `memcpy` the same packed layout in and out of frames, so a field
   added on one side and not the other silently mis-decodes on the wire.
3. Provides four functions: `uart_telemetry_init()`, `uart_telemetry_send_message()`,
   `uart_telemetry_read_message()`, `uart_telemetry_read_message_resync()`, plus the CRC helper.

## Frame layout

```
  offset  size  field
  ------  ----  --------------------------------------------------
     0     1    start_byte     always 0xAA
     1     1    msg_type       telemetry_msg_type_t
     2     1    payload_len    0 .. TELEMETRY_MAX_PAYLOAD_SIZE (64)
     3     2    seq            free-running counter, little endian
     5     N    payload        N == payload_len
   5+N     2    crc16          CRC-16/CCITT-FALSE over header+payload
   7+N     1    end_byte       always 0xBB
```

Total overhead is 8 bytes per frame. `crc16` covers the header **and** the payload — including
`start_byte` — so a corrupted length or type byte is caught, not just corrupted payload data.

The CRC is CRC-16/CCITT-FALSE: init `0xFFFF`, polynomial `0x1021`, MSB-first, no reflection, no
final XOR. `tools/ground_station/protocol.py` reimplements exactly this in Python; if you change
the polynomial or the init value here, that file has to change with it.

## Message types

| Value | Name | Direction | Payload |
|---:|---|---|---|
| 1  | `TELEMETRY_MSG_IMU` | FC → TM | `telemetry_imu_payload_t` |
| 2  | `TELEMETRY_MSG_BATTERY` | FC → TM | `telemetry_battery_payload_t` |
| 3  | `TELEMETRY_MSG_STATUS` | FC → TM | `telemetry_status_payload_t` |
| 10 | `TELEMETRY_MSG_CONTROL` | TM → FC | `telemetry_control_payload_t` |
| 11 | `TELEMETRY_MSG_ARMING` | TM → FC | (reserved; arming rides in the control frame) |
| 12 | `TELEMETRY_MSG_MODE` | TM → FC | (reserved; mode rides in the control frame) |
| 13 | `TELEMETRY_MSG_GAINS` | TM → FC | `telemetry_gains_payload_t` |
| 20 | `TELEMETRY_MSG_PID_DEBUG`  | FC → GS | `telemetry_pid_debug_payload_t` |
| 21 | `TELEMETRY_MSG_PID_GAINS`  | both | `telemetry_pid_gains_payload_t` |
| 22 | `TELEMETRY_MSG_PID_SELECT` | GS → FC | `telemetry_pid_select_payload_t` |
| 23 | `TELEMETRY_MSG_PID_INJECT` | GS → FC | `telemetry_pid_inject_payload_t` |

"GS" is the Python ground station in `tools/ground_station`. The `20..23` block is **tunnelled**:
the telemetry module does not interpret those frames at all, it forwards them verbatim between the
UART and a UDP socket (see `telemetry_module/components/gs_link`). That is why they are defined
here rather than in a ground-station-only header — the flight controller and the Python client
need the identical struct layout, and the telemetry module needs the type numbers to know what to
forward.

## The two independent PID loop numberings

There are **two** enums addressing the same eight PID instances, and this is deliberate:

- `telemetry_loop_id_t` — used by `TELEMETRY_MSG_GAINS` (the web dashboard). Ordered
  inner-to-outer: rate roll/pitch/yaw, angle roll/pitch, velocity x/y, altitude.
- `pid_loop_id_t` — used by the `PID_*` message block (the Python ground station). Ordered
  outer-to-inner: altitude, velocity x/y, angle roll/pitch, rate roll/pitch/yaw.

They were not unified because the dashboard's loop ids are baked into `index.html` as literal
numbers; renumbering `telemetry_loop_id_t` would silently retune the wrong axis from the browser.
`pid_registry_bind()` on the flight controller reconciles them — each PID instance keeps its
`telemetry_loop_id_t` array slot and is additionally *bound* to its `pid_loop_id_t`.

If you touch either enum, both sides break: grep for `telemetry_loop_id_t` (dashboard +
`flight_control.c`) and `pid_loop_id_t` (`pid_registry.c` + `tools/ground_station/protocol.py`).

## Compile-time size guards

The header ends in a block of `_Static_assert`s. There are two kinds and they exist for different
reasons:

- **Fits-in-a-frame** (`<= TELEMETRY_MAX_PAYLOAD_SIZE`) — without these, adding a field to a
  payload struct would overflow `telemetry_message_t.payload` at runtime and corrupt the frame
  tail. That presents as intermittent CRC failures, not as an obvious bug.
- **Exact size** (`== 30`, `== 25`, `== 4`, `== 10`, on the PID payloads only) — the Python ground
  station unpacks those with hardcoded `struct` formats (`"<IBB6f"` and friends). A compiler-
  inserted padding byte would still fit the frame and would still build; it would just shift every
  float in the plot by one byte and produce something that reads as noise rather than as a bug.

`TELEMETRY_MAX_PAYLOAD_SIZE` is 64 (raised from 48 so the 53-byte status frame fits).
`TELEMETRY_PID_PAYLOAD_CEILING` stays at 48 because the ground station's buffers are sized against
the old limit — the PID payloads are asserted against the tighter of the two.

## The two readers, and why you want `_resync()`

`uart_telemetry_read_message()` is the straightforward one: read header, validate, read payload,
read tail, check CRC. On **any** validation failure it calls `uart_flush_input()`.

That flush is the problem. It throws away not just the bad bytes but every good frame already
queued behind them. On a link carrying steady 50 Hz traffic, one corrupted byte therefore costs
several frames, and the flight controller's 300 ms control-link watchdog is only ~15 frames wide.

`uart_telemetry_read_message_resync()` never flushes. It scans forward one byte at a time looking
for `0xAA`, and on a bad length / bad end byte / CRC mismatch it simply continues scanning from
wherever it stopped. Worst case it loses the one frame it was mid-way through. It takes a total
time budget in milliseconds so a caller in a periodic task can bound how long it blocks.

**Use `_resync()` on both boards' RX paths.** The plain reader is kept because it is simpler and
is fine on a link with bursty request/response traffic, but nothing on this airframe has that
shape.

## Timing and concurrency

- `uart_telemetry_init()` installs the ESP-IDF UART driver with a 2 KB TX and 2 KB RX ring buffer
  and stores the port in a **module-global** (`active_uart_num`). Consequence: this component
  supports exactly **one** telemetry UART per firmware image. Both projects only need one.
- `sequence_counter` is also a plain module-global, incremented in `uart_telemetry_send_message()`
  with no lock. **All sends must come from one task.** Both firmwares comply (the flight
  controller sends only from `telemetry_task`, the telemetry module only from its UART TX task) —
  if you ever add a second sending task, the sequence numbers will interleave and the
  send-side CRC scratch buffer becomes a race.
- Reads and writes use the ESP-IDF driver's own ring buffers, so TX does not block on the wire as
  long as the buffer has room.
- Per-read timeouts inside the frame are hardcoded at 2 ms — long enough for a full 64-byte
  payload at the baud rates in use, short enough that a truncated frame does not stall a 50 Hz
  task.

## Public API

| Function | Purpose |
|---|---|
| `uart_telemetry_init(cfg)` | Configure port/pins/baud, install the driver. Call once. |
| `uart_telemetry_send_message(type, payload, len)` | Frame and write one message. |
| `uart_telemetry_read_message(out)` | Read one frame; flushes RX on error. |
| `uart_telemetry_read_message_resync(out, timeout_ms)` | Read one frame; resyncs instead of flushing. Preferred. |
| `telemetry_calculate_crc16(data, len)` | CRC-16/CCITT-FALSE. Exposed so callers can verify a frame they built themselves. |

Pins, port and baud rate are **not** defined here — each firmware passes its own
`telemetry_uart_config_t`. See `flight_controller/main/main.c` and
`telemetry_module/components/uart_link/include/uart_link.h`. Both are currently marked
`TODO(pins)` pending wiring confirmation, and they do not presently agree; confirm against the
actual harness before flashing.

## Dependencies

`esp_driver_uart`, `esp_driver_gpio`, `esp_timer` (the resync reader's deadline). No FreeRTOS
objects of its own.

## Files

| File | Contents |
|---|---|
| `include/telemetry_uart.h` | The entire contract: frame structs, message enum, payload structs, loop-id enums, flag bits, static asserts, function declarations. |
| `telemetry_uart.c` | CRC, driver init, framing on send, the two readers. |
| `CMakeLists.txt` | Component registration. |

## Changing this component

Any change ripples to three codebases. Before editing:

1. Read the "shared protocol" sections of both `flight_controller/CLAUDE.md` and
   `telemetry_module/CLAUDE.md`.
2. Grep the *other* firmware for the other side of your change.
3. If you touched a `PID_*` payload or either loop-id enum, update
   `tools/ground_station/protocol.py` too — it has its own hand-written copy of these layouts and
   the exact-size asserts here are the only thing that will catch a drift.

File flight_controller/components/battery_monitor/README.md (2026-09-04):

# battery_monitor

Pack voltage from a resistor divider on one ADC pin. Replaces the `battery_voltage = 3.8f`
constant that `flight_control.c` reported until 2026-09-03.

## Hardware

| | |
|---|---|
| Pin | **GPIO 14** (ADC2 channel 3) |
| Divider | 22 kΩ / 22 kΩ from pack+ to the pin to ground, ratio 2.0 |
| Decoupling | **100 nF** from the pin to ground |
| Attenuation | 12 dB, usable input roughly 150–3100 mV |

A 1S pack at 4.2 V through a 2:1 divider puts 2.1 V on the pin, with headroom at both ends.

### Why GPIO 14

ADC2 is unusable while Wi-Fi is running — which rules it out on the *telemetry module*, but this
board runs no Wi-Fi at all; it reaches the telemetry module over UART on GPIO 6/7. Every ADC1 pin
is already taken: motors on 1, 2, 4, 5; UART on 6, 7; PMW3901 SPI on 8, 9, 10. GPIO 3 is the only
free one and it is a strapping pin a divider would hold at half pack voltage through every boot.

Free alternatives: **15, 16, 17**. Avoid 19 and 20 (USB D-/D+). Changing `BATTERY_ADC_GPIO` is
sufficient — unit and channel are derived via `adc_oneshot_io_to_channel()`.

### Why 22k and not 100k

The 100 nF capacitor is Espressif's only *written* ADC recommendation — their ESP32-S3 schematic
checklist says to fit one, and the datasheet publishes no source-impedance limit at all. The
resistor choice is therefore ours to justify: 22 k/22 k gives an 11 kΩ Thévenin source and a
1.1 ms RC settling time, and draws 95 µA. 100 k/100 k would be 50 kΩ and 5 ms — probably still
fine given the cap, but with no specification to point at there is no reason to sit near the edge.

## Calibrating it

`BATTERY_TRIM` ships at `1.0f`, meaning *not yet measured*.

1. Power up on the pack, open the dashboard, read the **Batt** tile. (No serial needed — the board
   cannot take USB and pack power together.)
2. Multimeter across the pack terminals, motors off.
3. `BATTERY_TRIM = (meter volts) / (tile volts)`. Set it, reflash, confirm they agree.
4. Repeat near the bottom of a pack. A constant ratio means the trim is right; a ratio that
   changes means the divider is being loaded — fit smaller resistors.

The code has a scale factor and no offset, because a divider genuinely passes through zero. If one
ratio does not fit both ends, that is a hardware problem, not a second parameter to fit.

## How the number is made

Eight conversions, each converted to millivolts through the curve-fitting calibration, then
averaged. Per-conversion conversion matters because the calibration curve is non-linear —
averaging raw counts and converting once gives a different, wrong answer.

**No filtering.** The value jitters by tens of millivolts and sags under motor load, because that
is what the pack does. If a smoother display is wanted later, filter it in the dashboard rather
than here, so the log keeps the real signal.

If the calibration scheme is unavailable, `battery_monitor_init()` **fails** rather than
converting counts by a guess.

## The sanity gate

Pin readings outside 500–3000 mV return the 3.8 V nominal instead. A floating pin should read as
*no measurement*, not as a plausible battery.

Useful consequence: **a Batt tile pinned at exactly 3.80 V that never moves means the divider is
not working.** Anything else means it is reading.

## What is deliberately absent

No thrust compensation, no low-voltage cutoff, no warnings, and nothing in the control path reads
this. `motor_thrust_to_duty()` remains a plain linear map with no voltage term.

`battery_monitor_is_valid()` reports that the *hardware* works, not that the trim has been
measured. The dashboard tile is labelled "Batt (nom)" and dimmed; un-dim it once both hold.

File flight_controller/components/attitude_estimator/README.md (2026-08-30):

# `attitude_estimator` — complementary filter (roll / pitch / yaw)

Turns raw IMU samples into an attitude estimate: roll and pitch fused from accelerometer + gyro,
yaw integrated from the gyro alone. This is the innermost feedback signal in the whole aircraft —
`flight_control`'s rate loop reads `roll_rate/pitch_rate/yaw_rate` from here at 1 kHz and its angle
loop reads `roll/pitch` at 250 Hz.

Small component, ~140 lines, but the three things it decides — **axis mapping, sign convention,
and when the estimate is trustworthy** — are load-bearing for everything downstream.

## The fusion problem

| Sensor | Good at | Bad at |
|---|---|---|
| Accelerometer | Absolute reference — gravity says which way is down, no drift, ever | Only true when the drone isn't accelerating. Prop wash and manoeuvres make it garbage. Noisy. |
| Gyroscope | Smooth, fast, immune to linear acceleration | Integrating rate to angle accumulates bias. Drifts without bound. |

A complementary filter takes the high-frequency part from the gyro and the low-frequency part from
the accelerometer:

```
alpha = tau / (tau + dt)

roll  = alpha * (roll_prev  + roll_rate  * dt)  +  (1 - alpha) * roll_from_accel
pitch = alpha * (pitch_prev + pitch_rate * dt)  +  (1 - alpha) * pitch_from_accel
```

With `tau = 0.5 s` at 1 kHz, `alpha ≈ 0.998`. The gyro carries essentially all of the short-term
response; the accelerometer only pulls the long-term bias out over roughly half a second. Raising
`tau` trusts the gyro more (smoother, drifts more); lowering it trusts the accelerometer more
(more responsive to real tilt, but also to vibration).

`tau` is passed into `attitude_init()`, so it is tunable from `main.c` without touching this
component.

## Yaw has no absolute reference

**Yaw is pure gyro integration.** There is no magnetometer on this airframe, so nothing corrects
it. Yaw drift is unbounded — it will wander degrees per minute and never come back.

This is why yaw is flown as a **rate** everywhere in the cascade, never as an angle: there is no
angle PID for yaw, and `telemetry_control_payload_t.yaw_setpoint` is a rate in °/s.
`attitude_state_t.yaw` exists only so the dashboard can show a heading number; it is wrapped to
[-180, 180] and is otherwise not used by the controller.

**Do not build anything that assumes absolute heading.**

## The accelerometer low-pass and gate

The three accelerometer components are low-passed at **15 Hz** (first-order RC, alpha recomputed
from the measured `dt` each call), and both the gate and the angle calculation use the filtered
signal:

```
0.7 g  <=  |a_filtered|  <=  1.3 g
```

If the drone is genuinely stationary or in steady flight, gravity dominates and `|a| ≈ 1 g`.
During an aggressive manoeuvre `|a|` departs from 1 g and the derived angle is meaningless.
Outside the window the accelerometer is **gated out** for that sample: the filter coasts on pure
gyro integration and sets `accel_valid = false`.

### ⚠ Why the low-pass exists — it fixed a real drift bug (2026-08-29)

The gate used to run on the **raw** magnitude at 1 kHz, and the window was 0.8–1.2 g. Prop
vibration swings the instantaneous magnitude far past ±0.2 g, so most samples in powered flight
failed the gate, the filter degenerated into pure gyro integration, and gyro bias accumulated as
roll/pitch error over minutes. The pilot symptom was "after a few minutes the IMU accumulates a
lot of error on roll and pitch".

The 2026-08-27 flight log isolates it cleanly: **with motors off, drift was 0.0–0.3 °/min** — the
filter was never the problem. Drift appeared only under power. The accelerometer was not wrong, it
was being discarded.

Vibration is high frequency, gravity is DC, so the two are separable in frequency. Filtering
removes the interference; widening the gate alone would only have admitted the vibration into the
angle calculation, trading drift for noise. Simulated against 1 kHz sampling with tonal prop
vibration plus broadband noise:

| Vibration | Old gate accepts | LPF + new gate accepts | Mean per-sample roll error, raw → filtered |
|---|---|---|---|
| 0.2 g (mild) | 75.5% | 100% | 4.2° → 0.5° |
| 0.5 g (typical) | 35.7% | 99.9% | 13.4° → 1.3° |
| 1.0 g (harsh) | 25.0% | 99.0% | 30.7° → 2.7° |

The added phase lag is irrelevant here: the complementary filter already weights the accelerometer
at `(1 - alpha) = dt/(tau+dt)` ≈ 0.2% per sample, so it is only ever a long-term levelling
reference. Tens of milliseconds of lag against a 0.5 s time constant does not show up in the
output.

`ACCEL_LPF_CUTOFF_HZ = 15.0f` is a sensible starting point for a whoop, **not a measured value**.
If drift persists, lower it before touching the gate.

### Watching it work

`accel_valid` is **not** carried in the 50 Hz status frame, so neither the dashboard nor the
flight logs can show it — which is why this bug stayed invisible for so long. `attitude_update()`
therefore prints the accept ratio to the USB serial console once per second
(`ATTITUDE_HEALTH_LOG_ENABLED`). Spin the props on the bench and watch it: a healthy filter accepts
nearly everything. A low ratio means the cutoff is still too high.

The gate cannot catch a *sustained coordinated* acceleration where the magnitude stays near 1 g
while the direction is wrong — but that needs a precise bank angle held for seconds, which a
hand-flown whoop does not do.

## Initialisation gate

`attitude_state_t.initialized` becomes true only after **500 consecutive good accelerometer
samples** (0.5 s at 1 kHz of the drone sitting reasonably still). A gated-out sample does not
count toward the total, though it also does not reset it.

Two things happen during that window:

1. Roll and pitch are **seeded straight from the accelerometer** every sample rather than fused.
   Without this the filter would creep in from zero over its own time constant, and the first half
   second of flight would be spent fighting a bogus initial angle.
2. `attitude_is_initialized()` returns false, and **`flight_control` refuses to arm**. The state
   is also reported to the dashboard as `TELEMETRY_STATUS_FLAG_ATTITUDE_INIT`.

## ⚠ Axis mapping and signs are NOT verified

This is the most important unverified thing in the flight controller, and it is flagged in three
places (`attitude_estimator.h` field comments, a block comment in `attitude_update()`, and
`flight_controller/CLAUDE.md`).

The code assumes the IMU is mounted **X forward, Y right, Z up**, with the sensor's own axes not
rotated relative to the airframe:

```c
state.roll_rate  = imu->gyro_x_dps;
state.pitch_rate = imu->gyro_y_dps;
state.yaw_rate   = imu->gyro_z_dps;
```

That is an assumption about how the IMU sits on **your** PCB, and it is wrong about as often as
it is right.

### Bench check (props off, drone disarmed, watch the status telemetry)

| Move the airframe | Expected |
|---|---|
| Roll **right** | `roll_rate` goes **positive** |
| Pitch **nose up** | `pitch_rate` goes **positive** |
| Yaw **nose right** | `yaw_rate` goes **positive** |
| Hold right side down | `roll` goes **positive** |
| Hold nose up | `pitch` goes **positive** |

If an axis reads backwards, negate it in `attitude_update()`. If two axes are swapped, swap them
there. **Fix it here and it is fixed for the entire cascade** — do not compensate downstream in
`flight_control`, or the two corrections will fight each other later.

## Public API

| Function | Notes |
|---|---|
| `attitude_init(nominal_dt, tau)` | Clears state, stores `tau`. `nominal_dt` is validated but the actual per-call `dt` is what's used. Rejects non-positive arguments. |
| `attitude_update(&imu, dt)` | One filter iteration. Silently returns on `NULL` or non-positive `dt` — a skipped update is better than a corrupted state. |
| `attitude_get(&out)` | Struct copy of the current estimate. |
| `attitude_is_initialized()` | The arming precondition. |
| `attitude_reset()` | Clears state and forces re-init. Preserves `tau`. |

## Timing and concurrency

- `attitude_update()` runs in `fc_task` at 1 kHz, core 1, immediately after the IMU read. It is
  pure float arithmetic plus one `sqrtf` — no I/O, no allocation, no blocking.
- `dt` is passed per call rather than assumed, so jitter in the loop is absorbed correctly rather
  than integrated as an error.
- All state is module statics with **no locking**. Safe because `fc_task` is the only writer *and*
  the only meaningful reader. `telemetry_task` also calls `attitude_get()` for the status frame;
  that copy is not atomic, so a status frame can in principle mix fields from two consecutive
  1 kHz ticks. For a 50 Hz display of a slowly-changing quantity that is irrelevant — but it would
  not be acceptable if anything in a control path ever read it cross-task.

## Unverified assumptions and TODOs

| Marker | Location | What must be checked |
|---|---|---|
| `SIGN NEEDS BENCH VERIFICATION` | `attitude_estimator.h` (roll, pitch) | Angle sign convention |
| `AXIS MAPPING NEEDS BENCH VERIFICATION` | `attitude_estimator.h` (all three rates) | Gyro axis → body axis assignment |
| Block comment | `attitude_update()` | The full bench procedure, reproduced above |

The LPF cutoff (15 Hz), the gate window (0.7–1.3 g), `tau` (0.5 s) and the init sample count (500)
are reasonable starting values, not measured ones — but unlike the axis mapping, getting them
slightly wrong degrades performance rather than inverting a control loop.

That said, the cutoff is the one to watch: it is the constant that decides whether the
accelerometer participates in the fusion at all under power. The old raw-signal gate is proof that
getting this wrong is not a mild degradation — it silently turned a fused filter into a bare
integrator. Check the accept ratio in the serial log after any change to props, motors or frame.

## Dependencies

`imu_driver` (for `imu_physical_data_t` and `imu_compute_roll_pitch()`). Nothing else — no
FreeRTOS, no ESP-IDF drivers, no timers.

Consumed by `flight_control` (rates at 1 kHz, angles at 250 Hz), `sensor_task`/`nav_estimator`
(tilt compensation), and `telemetry_task` (status frame).

## Files

| File | Contents |
|---|---|
| `include/attitude_estimator.h` | `attitude_state_t` with its sign conventions, five public functions. |
| `attitude_estimator.c` | Gate constants, the filter, the axis-mapping bench procedure. |
| `CMakeLists.txt` | Component registration. |

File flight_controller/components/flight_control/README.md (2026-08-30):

# `flight_control` — the cascade, the mixer, arming, and the link watchdog

The orchestrator. Everything else on the flight controller either feeds this component or is
driven by it. It owns the eight PID instances, decides when motors are allowed to run, converts
three axis commands into four motor thrusts, and disarms the aircraft when the pilot's link goes
away.

`flight_control_update()` is called at exactly 1 kHz from `fc_task` and is the only thing that
writes the motors in normal operation.

## The cascade

Three nested loops, all clocked off the same 1 kHz tick using **divider counters** rather than
separate tasks — so they can never drift in phase relative to one another:

```
  OUTER    50 Hz   every 20 ticks   altitude  -> throttle
                                    velocity  -> angle setpoints
     ↓
  MID     250 Hz   every  4 ticks   angle     -> rate setpoints
     ↓
  INNER  1000 Hz   every    tick    rate      -> mixer -> motors
```

Why this shape:

- **Inner** needs to be fast — it is what actually stabilises the airframe, and it only needs the
  gyro, which is available every tick anyway.
- **Mid** at 250 Hz because angles change far more slowly than rates; running it at 1 kHz would
  cost cycles and gain nothing.
- **Outer** at 50 Hz because it is bounded by the sensors behind it (ToF at ~33 Hz, flow at
  100 Hz), and because altitude and position are slow quantities.

**Only the outer loop depends on `nav_estimator`.** It disengages itself the moment
`altitude_valid` or `velocity_valid` goes false. The mid and inner loops need only the IMU. That
is what makes the drone flyable in angle mode with no ToF and no optical flow fitted at all, and
what makes outer-loop hardware failures degrade gracefully instead of faulting.

### The eight PID instances

| Loop | Rate | Input → Output | Output limit | I-limit | D cutoff |
|---|---:|---|---|---|---|
| `RATE_ROLL` / `RATE_PITCH` / `RATE_YAW` | 1000 Hz | °/s → mix contribution | ±0.5 | 0.2 | 60 Hz |
| `ANGLE_ROLL` / `ANGLE_PITCH` | 250 Hz | ° → °/s | ±250 °/s | 50 | 30 Hz |
| `VEL_X` / `VEL_Y` | 50 Hz | m/s → ° | ±25° | 10 | 10 Hz |
| `ALTITUDE` | 50 Hz | m → throttle adjust | ±0.25 | 0.25 | 10 Hz |

The rate loops' ±0.5 output range is deliberately narrow: a single axis can never claim more than
half the motor range, which leaves room for the other two axes and the throttle. The D cutoffs
step down as you go outward — the rate loop sees raw gyro and needs the most filtering.

The array `pid_loops[]` is indexed by **`telemetry_loop_id_t`** (the web dashboard's ordering).
The ground station uses **`pid_loop_id_t`** (the opposite ordering). The `pid_loop_to_telemetry[]`
table near the top of `flight_control.c` is the single point where those two meet — nothing else
in the file needs to know both orderings exist.

### `flight_control_run_pid()`

Every PID call in the cascade goes through this one wrapper, which:

1. adds `pid_registry_inject_offset()` to the setpoint (the ground station's test signal), then
2. calls `pid_update()`, then
3. calls `pid_registry_publish()` to sample the controller's internals.

Both registry calls are non-blocking by construction — no lock, no UART, no logging — which is
what makes this safe in the 1 kHz path as well as the slower ones. `now_s` is taken **once** per
`flight_control_update()` so all three loops evaluate the same point on the injection waveform
within one tick.

## The mixer

### ⚠ Every sign in `flight_control_mix()` needs bench verification

This is the single most likely place for the drone to flip on its first flight.

```
        FRONT
   M0 ........ M1        M0 front-left  (CW)    M1 front-right (CCW)
   M2 ........ M3        M2 rear-left   (CCW)   M3 rear-right  (CW)
        REAR

  mix[M0] =  roll - pitch - yaw
  mix[M1] = -roll - pitch + yaw
  mix[M2] =  roll + pitch + yaw
  mix[M3] = -roll + pitch - yaw
```

The reasoning behind each column:

- **Roll** (+ = roll right, right side down): lift the **left** side → M0, M2 up / M1, M3 down.
- **Pitch** (+ = nose up): lift the **rear** → M2, M3 up / M0, M1 down.
- **Yaw** (+ = nose right): a motor spinning CW drags the frame CCW, so to rotate the frame CW we
  speed up the **CCW** motors → M1, M2 up / M0, M3 down.

**Bench check — props OFF, armed, a little throttle:**

| Command | Motors that must speed up |
|---|---|
| Roll right | M0 and M2 |
| Pitch up | M2 and M3 |
| Yaw right | M1 and M2 |

If an axis is backwards, flip the sign of that whole column. If the prop directions on your build
differ from the CW/CCW above, the **yaw column** is the one that changes.

### The three-step throttle placement

The mixer does not simply add throttle to the mix and clamp. That naïve version has a specific
failure mode this code is arranged to avoid: **a brushed motor commanded to zero has stopped, and
a stopped motor produces no control torque at all until it spins back up.** Clipping the low
motors to zero therefore destroys the attitude command precisely when the drone most needs it.

**Step 1 — fit the attitude command into the available band.** The usable band is
`[MOTOR_IDLE_THRUST, 1.0]`. If the spread the attitude loops asked for is wider, scale the **mix
only** down until it fits. Scaling the *differences* preserves the commanded attitude; scaling the
motor outputs (throttle included) would not, because it shrinks the differences by a different
proportion than it shrinks the average.

**Step 2 — place the throttle so nothing falls off either end.** Rather than clipping, shift the
whole group up so the lowest motor lands on the idle floor. That upward shift is capped at
`MAX_MIXER_THROTTLE_BOOST` (15 %) — without a cap this becomes full "airmode", and on a
button-driven throttle that means holding ALT− stops producing a descent. The cap is a deliberate
trade: pilot authority over the descent, at the cost of some attitude authority at very low stick.

**Step 3 — if the capped boost left us short, shrink the mix to fit.** `fit` scales all three axes
equally, so the *direction* of the commanded attitude is preserved and only its magnitude shrinks.
Authority degrades smoothly instead of two motors dropping out.

The final `clampf(..., 0, 1)` should never bite after those three steps. It is a safety net
against a NaN or a future edit, not load-bearing behaviour.

## Arming state machine

```
  DISARMED ──(arm requested + all gates pass)──> ARMED
     ↑                                             │
     └──(disarm / link lost / kill cleared)────────┘
     ↑
  KILLED ──(kill released AND arm released)────────┘
```

### Kill is absolute and latching

`TELEMETRY_CTRL_FLAG_KILL` immediately cuts motors and sets `kill_latched`. The latch clears only
when the pilot has **released kill AND is no longer asking to arm** — so letting go of the kill
button cannot by itself spin the motors back up. Kill is checked before the link watchdog and
before everything else.

### The arming gate — all four must hold

1. **No kill latch.**
2. **Link OK** — a valid control frame within the last 300 ms.
3. **Attitude initialised** — `attitude->initialized`, i.e. the complementary filter has settled.
   Normal to fail for the first half-second after boot.
4. **Throttle genuinely down** — below `ARM_THROTTLE_THRESHOLD` (0.02). This is what stops the
   drone leaping off the bench the instant it is armed.

This is the **only** path into `FLIGHT_STATE_ARMED`.

### Integrators are reset on arm *and* disarm

`flight_control_reset_all_pids()` runs on both. On disarm because whatever the integrators wound
up to while the drone was being wrestled to the ground is meaningless; on arm because time may
have passed and it is the last chance to guarantee a clean start.

### The single most important line in the file

```c
if (!motors_allowed) {
    flight_control_stop_motors();
    tick_counter = 0;
    return;
}
```

Every path that does not *explicitly* authorise the motors ends up here. Structuring it as a
single early return — rather than scattering conditionals through the cascade — is what makes
"disarmed means stopped" auditable.

## Disarmed monitor mode

`FLIGHT_CONTROL_MONITOR_WHEN_DISARMED` (default 1) runs the **outer loop only** while disarmed,
after the motors have already been stopped by the invariant above and before the early return. No
mid loop, no inner loop, no mixer, no motor write — the outer loop's only outputs are
`angle_setpoint_*` and `throttle_command`, and nothing that consumes those is running.

It exists to make the **unverified velocity→angle sign checkable without flying**. A wrong sign
there is positive feedback: the drone accelerates away from the hold point instead of settling.
Before this, the only way to find out was to engage position hold in the air.

### The bench procedure

Props off, drone powered, **disarmed**, ground station connected, PID tab on `Vel X` (then
`Vel Y`). Hold the drone 20–50 cm above a textured floor — on a desk the ToF sits outside its
0.03–1.30 m window, so `altitude_valid` is false and nothing computes. Press **HOLD** on the
dashboard, move the drone by hand, and read the published `output`:

| Move the drone | Loop | `output` must be | Because |
|---|---|---|---|
| Forward | `Vel X` | **negative** | negated at the call site → positive pitch = nose up = decelerate |
| Right | `Vel Y` | **negative** | used directly → negative roll = left wing down = decelerate |

The rule is the same for both axes: **move in the positive direction, the output goes negative.**
If it goes positive, that axis' sign is wrong, and in flight it is positive feedback.

> ⚠ `Vel X` is negated *after* `flight_control_run_pid()` returns, so the `output` in the PID trace
> is the value **before** negation. `Vel Y` is not negated. Read the table, not your intuition.

The Mode tile is live here too: it reads `POS HOLD` only when the loops genuinely engaged, so this
doubles as a way to see whether hold *would* engage at all without leaving the ground.

### Why it cannot reach the motors

`flight_control_stop_motors()` is called before it, and the function returns immediately after, so
no code path between the monitor and the motor driver is reachable. Integrators wound up while
monitoring are cleared by `flight_control_reset_all_pids()` on the way into `ARMED`, which also
clears both hold latches. It does not run while the kill latch is set.

It uses its own `monitor_tick_counter` rather than `tick_counter`, because the disarm path zeroes
that one every tick — sharing it would pin the monitor at "tick 0", running the outer loop at the
full 1 kHz while still passing `OUTER_LOOP_DT` (0.020 s) as its `dt` and making every rate in the
published trace wrong by 20×.

Set the macro to 0 for a build where a disarmed aircraft computes nothing at all.

### Idle cutoff

Armed but throttle below `MOTOR_IDLE_THRESHOLD` (0.05), and not in altitude hold: motors off,
integrators cleared. This stops the controller winding up against the ground before takeoff.

### Why `tick_counter = 0` on both stop paths

The divider counters are tested **before** they are incremented, so the very first tick after
arming (`counter == 0`) runs all three loops. Without the reset, `throttle_command` would still
hold the 0 left by `flight_control_reset_all_pids()` for the first 20 ticks, and the mixer's idle
floor would spin the motors on a throttle the pilot never commanded.

## Control-link watchdog

`LINK_TIMEOUT_US` is 300 ms. The telemetry module sends control frames at a fixed 50 Hz (20 ms),
so 300 ms tolerates **15 consecutive lost frames** — long enough to ride out a Wi-Fi hiccup, short
enough to matter if the pilot walks out of range.

`last_control_input_us == 0` (nothing has *ever* arrived) is explicitly not "link ok", so a board
that boots with no telemetry module attached can never arm.

`flight_control_set_control_input()` is called from `telemetry_task` on **core 0** while
`flight_control_update()` reads on **core 1**. The copy is done inside a `portMUX` critical
section on both sides — a torn read would mean acting on half of one frame and half of another,
e.g. the new throttle with the old kill flag.

## Flight modes

| Mode | Altitude | Roll/pitch sticks |
|---|---|---|
| `ANGLE` | Pilot throttle passed straight through | Angle setpoints directly |
| `ALT_HOLD` | Held by the altitude PID; stick becomes climb/descend around centre | Angle setpoints directly |
| `POS_HOLD` | Held | **Velocity** setpoints — centred sticks ask for zero velocity, which is what makes the drone hold station |

`TELEMETRY_CTRL_FLAG_HOLD` (the dashboard's hold toggle) requests both.

On engaging altitude hold, the current height is captured as the target and the altitude PID is
reset so it does not inherit anything from a previous engagement. In hold, throttle stick offset
beyond ±0.1 from centre moves the setpoint at up to `MAX_CLIMB_RATE_MS` (0.5 m/s), clamped to
0.05–1.20 m.

> **Velocity sign, unverified:** forward velocity error is corrected by pitching, and positive
> pitch is nose-up which moves the drone *backward* — hence the negation on `PID_LOOP_VEL_X`.
> Marked `SIGN NEEDS BENCH VERIFICATION`. If the drone runs away instead of holding station, this
> is the first thing to flip.

## Constants that must be measured

| Constant | Current | Why it matters |
|---|---|---|
| `MOTOR_IDLE_THRUST` | 0.12 | The floor every motor is kept at while armed. Must be above the duty at which the motor reliably starts. **Measure:** props off, arm, walk each motor up with `motor_set_thrust()` until all four start reliably from standstill; take the worst, add margin. |
| `HOVER_THROTTLE` | 0.45 | The altitude loop's output is added on top of this. A bad value means the loop spends its whole range correcting a constant offset. **Measure:** fly in angle mode, trim until it neither climbs nor sinks, read it off the dashboard. Expect 0.35–0.55 for a 1S whoop, depending on all-up weight with the camera. |
| All 12 default gains | see table | **Starting points, not answers.** Tune inside-out: rate loops first (P until it oscillates, back off ~30 %, then D, then a little I), then angle (P only to begin with), then velocity and altitude last. All are live-tunable from the dashboard. |

Other bounds — `MAX_ANGLE_SETPOINT_DEG` (25°), `MAX_RATE_SETPOINT_DPS` (250 °/s),
`MAX_ALTITUDE_THROTTLE_ADJUST` (0.25), `MAX_MIXER_THROTTLE_BOOST` (0.15) — bound how hard each
loop may push the one below it. They are conservative by design.

## Public API

| Function | Called from | Notes |
|---|---|---|
| `flight_control_init()` | `fc_task` startup | Inits all 8 PIDs, binds them to `pid_registry`, enters DISARMED. |
| `flight_control_update(&att, &nav, dt)` | `fc_task`, 1 kHz | The whole cascade. `nav` may be NULL. |
| `flight_control_set_control_input(&ctrl)` | `telemetry_task` | Spinlock-protected, cross-core safe. |
| `flight_control_get_status(&out)` | `telemetry_task` | Fills the status frame. |
| `flight_control_is_armed()` / `_get_state()` | anywhere | |
| `flight_control_set_gains(id, kp, ki, kd)` | `telemetry_task` | Dashboard tuning. **Preserves the integrator** (unlike `pid_registry_apply_gains()`). |
| `_set_rate_gains` / `_set_angle_gains` / `_set_velocity_gains` / `_set_altitude_gains` | | Convenience pairs — those axes are almost always tuned together. |

### Two notes on `flight_control_get_status()`

- `battery_voltage` is a **fixed 3.8 V**, not a measurement. There is no ADC divider on the pack
  and none is planned; it exists to keep the dashboard field populated. It will not fall as the
  pack drains, and nothing in the control path reads it.
- `loop_hz` is the **measured** inner-loop rate, counted over a 1-second window. It is there so
  you can confirm on the bench that this really is running at 1 kHz.

## Timing and concurrency

- `flight_control_update()` runs on **core 1** in `fc_task` at the highest priority. It must never
  block: no I/O, no mutexes, no logging in the hot path. The one log inside
  `flight_control_inner_loop()` (failed motor write) is rate-limited to once per second.
- `flight_control_set_control_input()` runs on **core 0** — the only cross-core write, protected
  by `control_input_spinlock`.
- `nav_state_t` arrives already copied out of `sensor_task`'s mutex by the caller, so this
  component never touches that lock.
- Live gain setters run on `telemetry_task` and write the PID structs directly with no lock. That
  is a tolerated race: a `float` write is atomic on this target, and the worst case is one
  iteration using a mixed gain set. The ground-station path (`pid_registry_apply_gains()`) *does*
  take a mutex, because it writes six coupled fields plus the integrator.

## Unverified assumptions and TODOs

| Marker | Location | What must be checked |
|---|---|---|
| `EVERY SIGN IN THIS FUNCTION NEEDS BENCH VERIFICATION` | `flight_control_mix()` | The mixer matrix — props off, per-axis |
| `SIGN NEEDS BENCH VERIFICATION` | `flight_control_outer_loop()` | Velocity→pitch negation |
| `TODO(bench)` | `MOTOR_IDLE_THRUST` | Measure the reliable-start duty |
| `TODO(bench)` | `HOVER_THROTTLE` | Measure the hover point |
| `TODO(tune)` | 12 default gains | Tune inside-out |

Upstream, and equally load-bearing: the gyro axis mapping in
[`attitude_estimator`](../attitude_estimator/README.md) and the prop CW/CCW directions in
[`motor_driver`](../motor_driver/README.md). A mixer sign error and an axis-mapping sign error
look identical from the outside — verify the estimator first, then the mixer.

## Dependencies

**Public** (`REQUIRES`): `pid_controller`, `motor_driver`, `attitude_estimator`, `nav_estimator`,
`telemetry_uart`, `esp_timer`.
**Private** (`PRIV_REQUIRES`): `pid_registry` — nothing in `flight_control.h` mentions it, because
the tuning registry is an implementation detail of the cascade.

## Files

| File | Contents |
|---|---|
| `include/flight_control.h` | `flight_state_t`, the cascade diagram, ten public functions. |
| `flight_control.c` | Loop rates, safety constants, default gains, the loop-id bridge table, the mixer, the arming machine, the three loops, status assembly, gain setters. |
| `CMakeLists.txt` | Component registration with the public/private dependency split explained. |

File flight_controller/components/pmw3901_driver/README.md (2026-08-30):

# `pmw3901_driver` — PixArt PMW3901 optical flow sensor (SPI)

The downward-facing optical flow sensor. It watches the floor and reports how far the image has
shifted since the last read, which `nav_estimator` combines with the ToF altitude to produce body-
frame velocity, which the outer loop uses for position hold.

## ⚠ The init sequence is now in — and that removed a safety property

`pmw3901_init()` used to return `ESP_ERR_NOT_SUPPORTED` from a deliberate stub. The stub is gone:
PixArt's 73-write power-up sequence now lives in `pmw3901_init_registers.h`, transcribed from
Bitcraze's MIT-licensed driver (provenance and licence are in that file's header).

**This driver has not yet been run against real hardware.**

While init always failed, `velocity_valid` was permanently false and the velocity outer loop could
never engage. The project relied on that. It is now gone: with a working ToF supplying
`altitude_valid`, `flight_control` **will** engage velocity hold using `FLOW_COUNTS_PER_RAD`
(still the guess `500.0f`) and the unverified gyro-compensation axis signs. A sign error there is
positive feedback — the drone accelerates away from the hold point rather than settling on it.

**Before flying this:** measure the scale factor and check the translation signs with
`../../../flow_calibration/`, then do the rotation half of the sign check on the drone (pitch in
place → `velocity_x` must stay near zero). Do not reflash the airframe until both pass.

### Third-party content

`pmw3901_init_registers.h` contains **Bitcraze's register values, not ours** (MIT, © 2017 Bitcraze
AB). Do not "tidy" them. The only correct way to change that table is to re-transcribe it from
upstream. Everything else in this component is project code.

## Hardware

| Item | Value |
|---|---|
| Host | `SPI2_HOST` |
| SCLK / MISO / MOSI | GPIO 18 / 8 / 9 |
| CS | GPIO 10, **driven manually** |
| Mode | SPI mode 3 (CPOL=1, CPHA=1) — PixArt requirement |
| Clock | 2 MHz maximum — PixArt requirement |

**Pins confirmed against the airframe wiring, 2026-08-29.** No longer placeholders. The full
allocation, verified by reading the drivers rather than a copied list:

| GPIO | Owner | Authority |
|---|---|---|
| 1, 2, 4, 5 | Motors (RL, RR, FL, FR) | `motor_driver.c:34-37` |
| 6, 7 | Telemetry UART TX/RX | `main.c:389-390` |
| 11, 12 | I²C SCL/SDA (IMU + ToF) | `imu_driver.c:34-35` |
| 13 | VL53L1X XSHUT | `vl53l1x_driver.c:52` |
| 8, 9, 10, 18 | Optical flow SPI | this component |

### ⚠ SCLK is on an underside pad

The ESP32-S3 Super Mini only breaks out **GPIO 1–13** on its side castellations — which is why
every other peripheral above lives in that range; there were no side pins left. GPIO 18 is
soldered to a **pad on the underside of the board**.

That joint has no strain relief and is the mechanically weakest electrical connection on the
aircraft. A lifted MISO or SCLK pad presents as a floating line — a constant `0x00` or `0xFF` —
which is exactly what the dual product-ID check catches at init. **If the sensor stops
identifying after a crash, suspect the solder joint before the code.** Hot-glue the wires down
once the ID check passes.

All five (`PMW3901_SPI_HOST` plus the four GPIOs) are `#ifndef`-guarded, so a bench harness can
override them from its own build without editing this component. `../../../flow_calibration/`
does exactly that via `idf_build_set_property(COMPILE_DEFINITIONS ...)`. The drone build defines
none of them and compiles identically to before the guards existed. Note the asymmetry with the
ToF: `vl53l1x_driver` *borrows* an I²C bus so its caller picks the pins at runtime, whereas this
component *creates* its SPI bus, so the pins can only be chosen at compile time.

> **Note:** the pin block in the source lists which GPIOs are taken elsewhere. That list is a
> convenience copy and had drifted out of date once already — treat `motor_driver.c`,
> `imu_driver.c` and `main.c` as authoritative for their own pins. The list above was
> re-verified against those files on 2026-08-29.

### Why chip select is manual

`spics_io_num` is `-1` and `pmw3901_cs_low()` / `pmw3901_cs_high()` drive the line by hand.

This is not a style preference. A PMW3901 register read is *send address → wait tSRAD → clock the
data byte out*, and **CS must stay low across the whole thing**. The ESP32's hardware CS deasserts
at the end of each SPI transaction, which would split that sequence in two and break it. Hence
manual CS, with a 1 µs settle either side.

## Register access

| Direction | Address byte | Sequence |
|---|---|---|
| Write | `reg \| 0x80` (MSB set) | one 2-byte transaction, then wait tSWW |
| Read | `reg & 0x7F` (MSB clear) | address byte → wait tSRAD → data byte, CS low throughout, then wait tSRR |
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

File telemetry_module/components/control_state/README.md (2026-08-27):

# `control_state` — buttons into setpoints

The pilot's dashboard has **no joysticks**. It has buttons you press and hold. This component is
what turns "the roll-right button is currently down" into "roll setpoint = 11.3°" — and it is the
only place on either board where that synthesis happens.

It also holds the last status frame received from the flight controller, so the HTTP layer has
something to serve to the dashboard without touching the UART.

## Ramp on hold, decay on release

While a button is held, its axis **ramps** toward the axis limit. When released, it **decays**
back to neutral:

```
  held    →  ramp_towards(±limit,  ramp_rate,  dt)
  released→  ramp_towards(   0,   decay_rate, dt)
```

**Decay is deliberately about 2× the ramp rate.** Letting go should always settle the drone faster
than pressing made it move — that asymmetry is what makes a button interface flyable at all.
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

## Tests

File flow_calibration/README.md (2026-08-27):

# `flow_calibration` — PMW3901 optical flow scale bench tool

An ESP-IDF project that runs on a **spare ESP32-S3**, not on the drone. It measures
`FLOW_COUNTS_PER_RAD` for
[`../flight_controller/components/nav_estimator/nav_estimator.c`](../flight_controller/components/nav_estimator/nav_estimator.c),
which currently holds the guess `500.0f`.

Sibling of [`../tof_calibration`](../tof_calibration/) and built the same way. Bench tooling, not
aircraft firmware.

## ⚠ Read this before flashing the drone

Completing the PMW3901 driver removed a safety property the project was relying on.

While `pmw3901_init()` always failed, `velocity_valid` was permanently false and the velocity
outer loop could never engage. That is no longer true. With the ToF now supplying
`altitude_valid`, `flight_control` **will** engage velocity hold using the unmeasured
`FLOW_COUNTS_PER_RAD` and the unverified gyro-compensation signs. A sign error there is positive
feedback: the drone accelerates away from the hold point instead of settling on it.

**Do not reflash `flight_controller` until:**

1. `FLOW_COUNTS_PER_RAD` has been measured with this tool, and
2. the translation signs check out here, and
3. the rotation signs check out on the drone (pitch in place → `velocity_x` stays near zero).

## The math — and a correction to the documented procedure

`nav_estimator.c` used to say `angle_moved_rad = atan2(D, h)`. **That was wrong.** The sensor
accumulates frame-to-frame image shifts, so a slide of distance `D` at height `h` accumulates
`∫(v/h)dt = D/h`. `atan(D/h)` is the angle subtended at the *end* position, which is not what
accumulates.

It is also what the downstream arithmetic requires: `velocity = (counts/K)/dt · altitude` only
recovers the true `D/dt` when `counts/K = D/h`. The "rad" in the constant's name is really tangent
units (pixel displacement) — the pinhole relation.

```
FLOW_COUNTS_PER_RAD = accumulated_counts × h / D
```

With the old comment's own numbers (`D=200, h=300`), `atan` gives `0.588` against the correct
`0.667` — `K` came out 13% high and estimated velocity 13% low. The comment in `nav_estimator.c`
has been corrected.

Keeping `D/h ≲ 0.3` makes the two forms agree to ~1%, so the defaults here are specified that way
and the distinction can't bite regardless of lens non-idealities.

## What you need

| Item | Notes |
|---|---|
| Spare ESP32-S3 | Pins configurable — see below |
| PMW3901 breakout | |
| A rigid slide | A straightedge, a drawer runner, a book edge — anything that constrains motion to a straight line **without rotating** |
| A spacer of known height | Sets `h`. Measure from the **lens**, not the PCB |
| A textured surface | Newspaper, patterned rug, wood grain. Not plain carpet, not glossy laminate, not blank paper |
| A ruler | `K = counts·h/D`, so errors in `h` and `D` contribute equally and linearly |

### The whole field of view must see ONE flat plane

The most damaging rig mistake, because it produces a plausible number rather than an obvious
failure. The sensor correlates its entire 30×30 frame at once, and image shift scales as `ΔX/h` —
so two surfaces at different depths in the same frame flow at *different rates*, and you get one
blended answer weighted by whichever has more contrast.

It is disproportionately bad, because a nearer surface flows faster. A sensor overhanging a table
edge to look at the floor 890 mm below, catching the tabletop (155 mm below) in just 10% of the
frame:

```
0.9 × (1/890) + 0.1 × (1/155) = 0.001656   vs   true 1/890 = 0.001124   →  +47%
```

Ten percent intrusion, ~47% error. `squal` may or may not flag it.

Clearance needed is `h × tan(21°)` — at 890 mm that is 341 mm of horizontal clearance to the
nearest other surface, **plus** the slide travel. Which is why looking down at a nearby surface
(newspaper on the table, sensor on a short stand above it) is almost always the better rig than
looking down at something far away past an obstruction.

Field-of-view patch diameter is `2 × h × tan(21°)`: 119 mm at h=155, 307 mm at h=400, 683 mm at
h=890. The textured area must cover the whole patch.

## Wiring

Defaults here are set for a **XIAO ESP32-S3**, per
[`../documents/XIAO_ESP32-S3_front_pinout.png`](../documents/XIAO_ESP32-S3_front_pinout.png):

| Signal | GPIO | Pad | Note |
|---|---|---|---|
| SCK | 7 | D8 | silkscreen `SPI0_SCK` |
| MISO | 8 | D9 | `SPI0_MISO` |
| MOSI | 9 | D10 | `SPI0_MOSI` |
| CS | 4 | D3 | any free pin — bit-banged by the driver, not the SPI peripheral |
| VIN | — | 3.3V-OUT | **not** VBUS; the PMW3901 is a 3.3 V part |
| GND | — | GND | |

Note these are **not** the driver's own defaults (`SCLK 18 / CS 10`). The XIAO ESP32-S3 breaks out
only 11 GPIOs — 1–9, 43, 44 — so GPIO 18 and GPIO 10 do not physically exist on it. See the
"drone pin map" warning below.

The "SPI0" labels are Seeed's Arduino naming. On the ESP32-S3, SPI0/SPI1 belong to flash and
PSRAM; the driver uses `SPI2_HOST` and the GPIO matrix routes it to those pads.

**Change them in [`CMakeLists.txt`](CMakeLists.txt)**, not in the driver:

```cmake
idf_build_set_property(COMPILE_DEFINITIONS "PMW3901_PIN_SCLK=18" APPEND)
```

Those five `#define`s are `#ifndef`-guarded in `pmw3901_driver.c`, so this build overrides them
and the drone's firmware is untouched. `main.c` prints the compiled-in values at boot, so the
serial log always shows what actually got built.

This differs from the ToF tool, where `main.c` chose the I²C pins directly. `vl53l1x_driver`
*borrows* a bus; `pmw3901_driver` *creates* one, so its pins are compile-time only.

Avoid the strapping pins (0, 3, 45, 46) and the USB-JTAG pins (19, 20).

## Frame view — check what's actually in shot first

Before trusting any trial, verify the field of view is clean. In [`main/main.c`](main/main.c):

```c
#define CAL_FRAME_VIEW 1
```

Rebuild, reflash, and the tool prints the sensor's raw 35×35 image as ASCII art once a second
instead of running trials. Contrast is auto-scaled to the frame's own min/max, because the
PMW3901's raw levels sit in a narrow band that shifts with lighting — a fixed ramp just renders
flat grey.

- **What you want:** uniform texture filling the whole frame.
- **What to eliminate:** a straight edge, a bright blob, or a dark region that *doesn't move*
  when you slide the rig. That's the table edge or the clamp.

This is a **separate build on purpose.** Entering frame mode permanently disables motion
reporting until the sensor is power-cycled, so the modes can't be confused at runtime. Set
`CAL_FRAME_VIEW` back to `0`, rebuild and reflash before running trials.

A frame takes ~0.5 s to read (1225 pixels, two SPI reads each), so it's a static check, not a
live viewfinder.

**The view is wider than the region that actually matters.** The readout is 35×35, but the
correlator computes flow over 30×30 — so clutter right at the frame edge may not be corrupting
anything. The check errs on the safe side: a clean frame definitely means a clean measurement, but
a slightly cluttered edge isn't automatically a reason to rebuild the rig. Clutter anywhere near
the centre is.

## Running it

```bash
idf.py set-target esp32s3
```

```bash
idf.py -p /dev/ttyACM0 flash monitor
```

(Source your ESP-IDF `export.sh` first.)

Set `CAL_HEIGHT_MM` and `CAL_SLIDE_MM` in [`main/main.c`](main/main.c) to match your rig — they go
directly into the result.

There is no countdown and no fixed window. **Slide mark to mark in about a second, let go, and
wait for the result to print.** The trial ends itself once the rig has moved and then been
stationary for 1.2 s. Then slide it back — that's simply the next trial, in the opposite
direction, and equally valid. Take the magnitude.

Two things the tool now checks for you, both learned the hard way:

- **Reversal.** A clean one-way slide ends at its own peak excursion. If the net comes back well
  below the peak, the rig moved again before settling — usually the return trip starting early —
  and the net is the *difference* of two slides, not one. The report says so; discard that trial.
- **Counts per read.** The sensor reports *integer* deltas. A slide slow enough that each read
  sees a fraction of a count can lose displacement and bias `K` **low**. A 30 mm slide taken over
  10 seconds is only ~0.09 counts per read — almost every read returns zero. Aim comfortably above
  1; the report warns below 0.5. This is why "slide briskly" matters, and it is *not* fixable by
  polling slower — the delta register accumulates between reads, so the loss is internal to the
  sensor and depends on speed alone.

**Keep the sensor flat.** There is no IMU on this rig, so there is no gyro compensation. Any tilt
or rotation during the slide goes straight into the measured constant as error.

## Reading the output

Each trial reports accumulated `dx`/`dy`, a `K` candidate for each axis, and surface-quality
stats. Slide along one axis at a time: a forward slide makes `dx` the meaningful number, a
rightward slide makes it `dy`.

The tool **accumulates low-quality reads rather than discarding them** — dropping them would throw
away real displacement and bias `K` low. Instead it reports how many were below the advisory
`squal` threshold, so a bad surface shows up as a reason to re-run rather than as a silently wrong
number.

It also gives you the translation half of the sign check for free: `nav_estimator` expects forward
→ `+dx` and right → `+dy`. The trial output states what was actually observed.

Sanity check: the published figure for this part's ~42° field of view over 30×30 pixels lands near
500. That is a smell test, not a target — measure your own unit.

## Files

| File | Contents |
|---|---|
| `CMakeLists.txt` | Pulls in `pmw3901_driver`; **SPI pin overrides live here** |
| `sdkconfig.defaults` | Minimal, plus the 1 kHz tick the driver's bring-up delays need |
| `main/main.c` | Trial loop and the arithmetic |

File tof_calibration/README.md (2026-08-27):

# `tof_calibration` — VL53L1X offset calibration bench tool

A throwaway ESP-IDF project that runs on a **spare ESP32-S3**, not on the drone. It exists to
produce one number: the value for `VL53L1X_OFFSET_MM` in
[`../flight_controller/components/vl53l1x_driver/vl53l1x_driver.c`](../flight_controller/components/vl53l1x_driver/vl53l1x_driver.c),
which is currently `0` and marked `TODO(bench)`.

This is a third firmware project in the repo, built separately like the other two. It is a bench
tool, not part of the aircraft.

## Why a separate project rather than doing it on the drone

- `VL53L1X_CalibrateOffset()` is a one-off ST ULD call that `vl53l1x_driver`'s public API
  deliberately does not wrap — it is a bench step, not runtime code.
- The drone's `vl53l1x_init()` borrows the I²C bus `imu_setup()` creates, so calibrating in place
  means bringing up the IMU, `sensor_task`, and the whole control stack — with four live motor
  outputs — while holding a grey card 140 mm from the sensor.

## What it reuses, and why that matters

It does **not** copy the driver. The top-level `CMakeLists.txt` points `EXTRA_COMPONENT_DIRS` at
the `vl53l1x_driver` component directory itself, so this project compiles the same source the
drone flies, including ST's vendored ULD in `st_uld/`.

That is load-bearing, not just tidiness: **the offset is only valid for the ranging configuration
it was measured under.** By calling the real `vl53l1x_init()`, calibration runs at short mode /
20 ms timing budget / 25 ms inter-measurement — exactly what flies. A hand-rolled init would give
a number that is subtly wrong in the air.

The one thing this project does differently: `main.c` creates the I²C bus itself, standing in for
the drone's `imu_setup()`.

> Note on `EXTRA_COMPONENT_DIRS`: it points at the single component directory, **not** at
> `flight_controller/components/`. Pointing at the folder would discover every component, and
> `flight_control` / `pid_registry` require `telemetry_uart` from `../shared_components`, which is
> not on this project's search path — a configure-time failure.

## What you need

| Item | Notes |
|---|---|
| Spare ESP32-S3 | Any board; pins below are configurable |
| VL53L1X breakout | The same part that goes on the drone, ideally **with the same cover glass** — see caveat below |
| 17 % grey target | ST's spec. A grey card from a photography set is the correct thing. Failing that, matte mid-grey card stock; avoid white paper (too reflective) and gloss (specular). |
| A ruler | The accuracy of the whole procedure is the accuracy of this measurement |

## Wiring

| Signal | Default GPIO | Change it in |
|---|---|---|
| SDA | 12 | `CAL_I2C_SDA_GPIO`, `main/main.c` |
| SCL | 11 | `CAL_I2C_SCL_GPIO`, `main/main.c` |
| XSHUT | **13** | `VL53L1X_XSHUT_GPIO`, `vl53l1x_driver.c` — see below |
| VIN / GND | 3V3 / GND | |

SDA/SCL default to the drone's pins for familiarity, but nothing about the offset depends on which
pins the bus runs on — change them to whatever is convenient on the spare board.

**XSHUT is the exception.** It is hardcoded to GPIO 13 in `vl53l1x_driver.c`, which this project
compiles unmodified.

These three numbers are the *drone's*, and they reach the sensor through the custom frame PCB — a
bare dev board will not necessarily break all of them out. On a XIAO ESP32-S3 in particular the
header exposes a restricted GPIO set and 13 may not be available at all. So:

- **Easiest path: tie XSHUT to 3V3.** The driver's reset pulse then lands on an unconnected
  GPIO 13 and is a harmless no-op; the sensor comes up on power-on reset instead.
- Or wire XSHUT to GPIO 13 if the board exposes it, which also exercises the drone's assumption.

**Do not leave XSHUT floating** — the part may stay in reset and `vl53l1x_init()` will report
that it never booted. (Many breakouts pull it up, but do not rely on it.)

If SDA 12 / SCL 11 are not broken out either, just change the two `#define`s — nothing about the
offset depends on the bus pins.

## Running it

```bash
idf.py set-target esp32s3
```

```bash
idf.py build
```

```bash
idf.py -p /dev/ttyACM0 flash monitor
```

(Source your ESP-IDF `export.sh` first if `idf.py` is not on your PATH.)

The program runs in four phases:

1. **Bus + init** — creates I²C, then calls the real `vl53l1x_init()`.
2. **Positioning aid** — 20 seconds of live *uncalibrated* readings, twice a second, while you set
   the target at exactly 140 mm. Set the distance with the ruler; the printed number is not
   supposed to read 140 yet — that is the entire point of calibrating.
3. **Pre-check** — averages 30 samples and warns if the result is more than 40 mm from the target
   (almost always means the ruler and `CAL_TARGET_DISTANCE_MM` disagree) or if samples are coming
   back invalid.
4. **Calibrate + verify** — runs ST's routine (it averages 50 measurements internally), prints the
   offset in a box, then restarts ranging and streams *calibrated* readings so you can check two
   known distances against the ruler.

## Then update the flight firmware

Take the printed number to `vl53l1x_driver.c:61` and replace the zero:

```c
#define VL53L1X_OFFSET_MM <the number>
```

Also worth updating at that point: the `TODO(bench)` comment block above it, and the
unverified-assumptions table in the component's `README.md`.

## Caveats worth knowing before you trust the number

- **Cover glass dominates this measurement.** The offset ST is correcting is mostly caused by
  whatever sits in front of the sensor. If the drone has a canopy, camera glass, or a printed
  mount over the ToF and the bench rig does not, the number you measure here is not the number the
  drone needs. Calibrate with the flight cover glass in place, or accept that this gets you closer
  than `0` but not all the way.
- **It corrects a constant, not a slope.** Offset calibration fixes a fixed bias. If readings drift
  proportionally with distance, that is a crosstalk problem — `VL53L1X_CalibrateXtalk()` in
  `st_uld/VL53L1X_calibration.c`, a separate procedure this tool does not run.
- **140 vs 100 mm.** `CAL_TARGET_DISTANCE_MM` is 140, matching the component README. ST's own
  `VL53L1X_calibration.h` suggests 100. Either works — the only hard requirement is that the
  `#define` equals the distance you physically measure, since ST computes
  `offset = target − average_measured`.
- Ambient IR matters. Short mode is chosen partly for this, but do not calibrate in direct
  sunlight.

## Files

| File | Contents |
|---|---|
| `CMakeLists.txt` | Pulls in `vl53l1x_driver` by pointing at the component directory |
| `sdkconfig.defaults` | Minimal — deliberately **not** a copy of the flight controller's |
| `main/main.c` | The four-phase procedure |

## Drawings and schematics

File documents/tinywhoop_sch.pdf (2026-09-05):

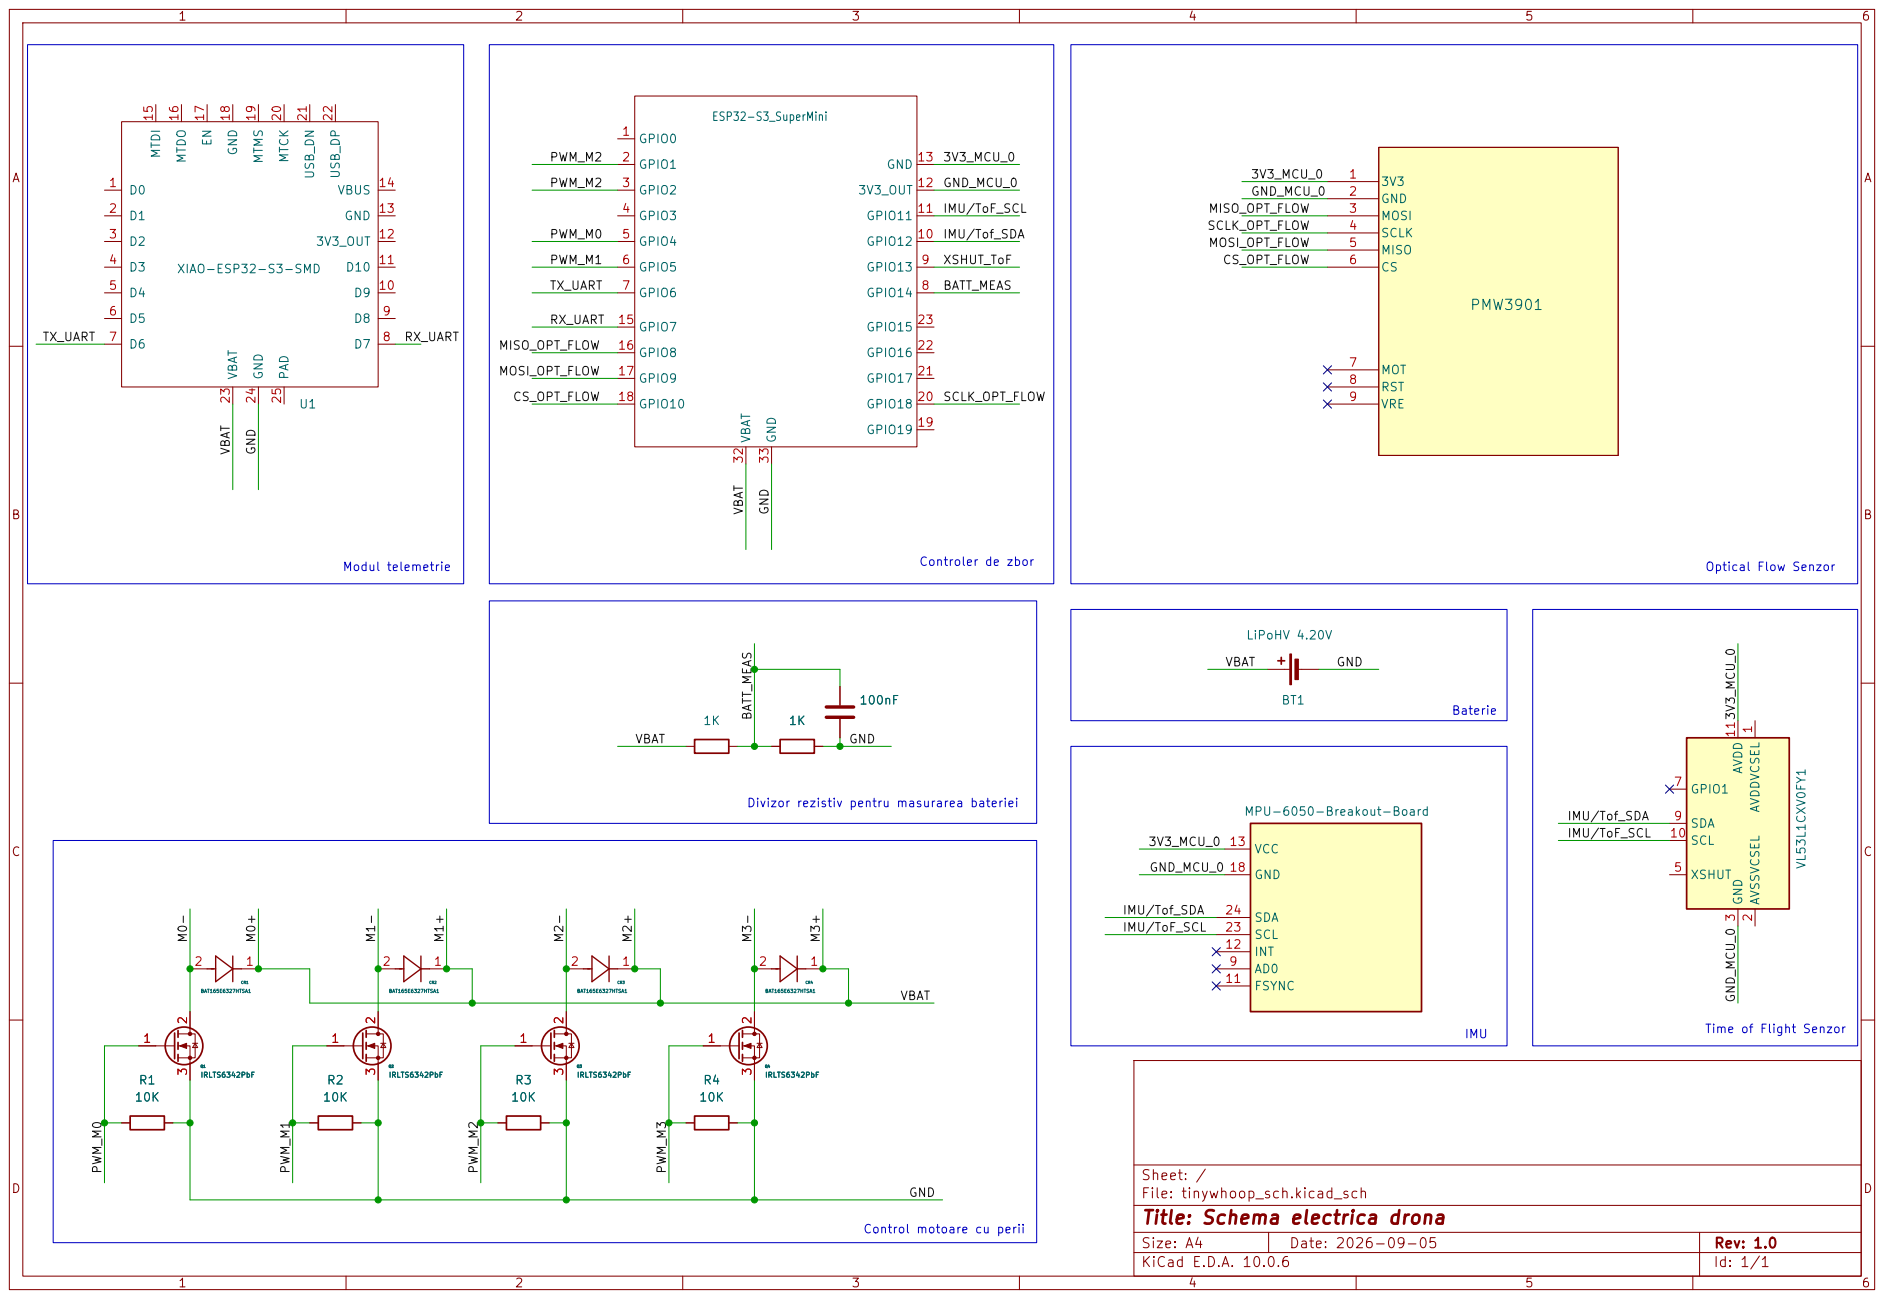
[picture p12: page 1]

Baterie Divizor rezistiv pentru masurarea bateriei 100nF 1K

Sheet: /
File: tinywhoop_sch.kicad_sch
Title: Schema electrica drona

Size: A4 | Rev: 1.0
KiCad E.D.A. 10.0.6 | Id: 1/1

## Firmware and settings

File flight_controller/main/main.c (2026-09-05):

// main.c - the flight controller's entry point: startup ordering and the three FreeRTOS tasks.
//
// WHAT THIS FILE DOES
//   No control logic of its own. It creates the tasks, brings the components up in an order that
//   is dictated by hardware dependencies, and owns the cross-task plumbing.
//
//     fc_task         core 1, top priority, 1000 Hz - IMU -> attitude -> nav snapshot -> cascade
//     sensor_task     core 0, prio 6,        100 Hz - lives in sensor_task.c
//     telemetry_task  core 0, prio 5,         50 Hz - status/debug/IMU out, control+tuning in
//
//   The split is by TIMING SENSITIVITY, not by subject. fc_task gets core 1 (APP_CPU) because
//   core 0 (PRO_CPU) runs Wi-Fi, lwIP and IDF background work; the two slow tasks go on core 0
//   precisely because their I/O blocks.
//
// THE ONE RULE THAT SHAPES EVERYTHING HERE
//   The 1 kHz side never waits. Every cross-task read in fc_task uses a ZERO timeout and carries
//   on with its previous copy on failure. Stale data by one cycle is always preferable to a
//   missed 1 ms deadline.
//
// STARTUP ORDER IS NOT ARBITRARY - see the comments in app_main(). Two constraints drive it:
//   1. Motors must be configured and driven to zero before any code can command thrust.
//   2. The ToF sensor attaches to the I2C bus that imu_setup() CREATES, and imu_setup() runs
//      inside fc_task - hence imu_ready_semaphore, which app_main blocks on before starting the
//      navigation sensors.
//

#include <stdio.h>
#include <math.h>
#include "freertos/FreeRTOS.h"
#include "freertos/task.h"
#include "freertos/semphr.h"
#include "esp_log.h"
#include "imu_driver.h"
#include "esp_timer.h"
#include "telemetry_uart.h"

#include "attitude_estimator.h"
#include "nav_estimator.h"
#include "motor_driver.h"
#include "battery_monitor.h"
#include "flight_control.h"
#include "pid_registry.h"
#include "sensor_task.h"

#ifndef M_PI
#define M_PI 3.14159265358979323846
#endif

static const char *TAG = "FC_MAIN";
// #define ALPHA 0.70

// How many PID debug samples the telemetry task forwards per 20 ms cycle. 32 covers 1600
// samples/second, comfortably above the 500 Hz the ground station asks for at its fastest
// setting, so the queue only backs up if the UART itself is the bottleneck.
#define PID_DEBUG_PER_CYCLE 32

// ===========================================================================
// MOTOR BENCH MODE - measuring MOTOR_IDLE_THRUST
//
// Set MOTOR_BENCH_MODE to 1 and app_main() brings up the motor driver and NOTHING ELSE: no
// IMU, no estimators, no flight control, no UART, no arming gate. Set it back to 0 before
// flying. Left on by accident the firmware does not fly badly - it does not fly at all, which
// is the failure mode you want from a switch like this.
//
// WHAT IT DOES
//   Holds the motors at exactly BENCH_THRUST, cycling BENCH_ON_MS on and BENCH_OFF_MS off,
//   forever. Nothing ramps and nothing changes on its own: the only number that reaches the
//   motors is the one written below. To test another value, edit it, reflash, watch again.
//
// WHY IT CYCLES INSTEAD OF JUST HOLDING
//   The quantity being measured is "does this motor start RELIABLY from a dead stop", and one
//   successful start does not answer that. Every on-transition is a fresh start attempt from
//   rest, so watching ten cycles gives ten trials. A motor that catches on eight of ten is
//   telling you this thrust is below its real floor, which a single hold would hide completely.
//
// WHAT TO LOOK FOR
//   All four motors starting on EVERY cycle, promptly, without a stutter or a nudge. A motor
//   that hesitates, or starts on some cycles and not others, has not met the bar. The lowest
//   value at which all four pass every cycle is the answer.
//
// PROPS STAY ON. Against the usual bench rule, deliberately: a coreless brushed motor needs
//   materially more torque to start under a prop's load than bare, so a bare-shaft measurement
//   returns a number that is too low - the same direction of error already in the code.
//   RESTRAIN THE AIRFRAME and keep hands and face clear. BENCH_THRUST is never near hover, but
//   restraint is still the only safe way to run this.
//
// SUGGESTED SEQUENCE (bisection - about four flashes rather than eight)
//   0.12 is known to work: all four already start at it, since that is what the mixer floors
//   them to today. So start below it and bisect.
//
//     0.06  -> all four start every cycle?  no  -> try 0.09
//     0.09  -> all four start every cycle?  yes -> try 0.075
//     0.075 -> ...                          no  -> try 0.08
//     0.08  -> ...                          yes -> answer is 0.08
//
//   Then add a little margin for a tired pack and a cold motor: round UP, and prefer the value
//   that still worked to the one that just barely did.
//
// PACK VOLTAGE MATTERS
//   Start duty depends on pack voltage, so a value that passes on a full pack can fail on a
//   half-empty one. Take the measurement on a freshly charged pack, and if a value is
//   borderline, re-check it near the end of a pack before trusting it.
// ===========================================================================
#define MOTOR_BENCH_MODE 0

// The thrust command under test. This is the ONLY value that reaches the motors.
#define BENCH_THRUST 0.06f

// Which motor: 0-3 for one on its own, or -1 for all four together.
// All four together is usually what you want - they then see the same pack voltage at the same
// instant, so a motor that needs more than its siblings shows up directly as the odd one out.
#define BENCH_MOTOR (-1)

// On and off times for one trial. 2.5 s on is long enough to see and hear clearly; 2 s off is
// long enough for a coreless motor to come fully to rest, which is what makes the next
// on-transition a genuine start from dead stop rather than a re-acceleration.
#define BENCH_ON_MS  2500
#define BENCH_OFF_MS 2000

static SemaphoreHandle_t imu_data_mutex;
static telemetry_imu_payload_t latest_imu_payload;

// Signalled by fc_task once the IMU is up and calibrated. app_main waits on this before
// initialising the navigation sensors, because the VL53L1X shares the I2C bus that
// imu_setup() creates and must not touch it first.
static SemaphoreHandle_t imu_ready_semaphore;

// THE 1 kHz CONTROL TASK. Core 1, highest priority, and the only writer of the motors.
//
// Startup half: owns the IMU end to end (setup + both calibration sweeps), then signals
// imu_ready_semaphore so app_main can bring up the sensors that share the I2C bus it just made.
//
// Loop half, per 1 ms tick:
//   read IMU -> convert -> compute dt -> publish the IMU telemetry snapshot (zero-timeout mutex)
//   -> attitude_update/get -> grab the latest nav state (zero-timeout mutex) -> run the cascade.
//
// Nothing slow is permitted past the startup half: no logging in the steady-state path, no
// blocking mutex take, no I/O other than the single IMU burst read.
void fc_task(void *args) { //semnatura unui task freeRTOS trebuie sa contina un param de tip void*
    ESP_LOGI(TAG, "Flight controll task started on core %d", xPortGetCoreID());
    //init imu, pwm
    esp_err_t error = imu_setup();
    if (error != ESP_OK) {
        ESP_LOGE(TAG, "IMU setup failed: %s", esp_err_to_name(error));
        vTaskDelete(NULL);
        return;
    }
    // float roll_offset = 0.0f, pitch_offset = 0.0f;
    imu_calibrate_acc();
    imu_calibrate_gyro();

    // The IMU is up and the I2C bus exists - app_main can now bring up the ToF and the flow
    // sensor without racing us for the bus.
    if (imu_ready_semaphore != NULL) {
        xSemaphoreGive(imu_ready_semaphore);
    }

    // 1 tick == 1 ms because CONFIG_FREERTOS_HZ is 1000 (see sdkconfig.defaults).
    // NOTE: this used to be pdMS_TO_TICKS(1000), which is 1000 ms, so the "1 kHz" loop was
    // actually running at 1 Hz. Raising the tick rate is what makes 1 kHz reachable at all.
    const TickType_t xFreq = pdMS_TO_TICKS(1); // 1ms -> 1kHz
    TickType_t xLastWakeTime = xTaskGetTickCount();
    int64_t last_time = esp_timer_get_time();


    imu_raw_data_t imu_raw_data;
    imu_physical_data_t imu_physical_data;

    float roll_angle = 0.0f, pitch_angle = 0.0f;
    // float roll_angle_comp = 0.0f, pitch_angle_comp = 0.0f;

    attitude_state_t attitude;
    nav_state_t nav_state = {0};   // retained between iterations if the mutex is busy

    for (;;) {
        error = imu_read_raw_data(&imu_raw_data);
        if (error != ESP_OK) {
            ESP_LOGE(TAG, "IMU read failed: %s", esp_err_to_name(error));
            // A dead IMU means no attitude, which means the drone must not be flying.
            motor_all_stop();
            vTaskDelay(pdMS_TO_TICKS(10)); // wait a bit before retrying
            continue;
        }
        imu_convert_raw_to_physical(&imu_raw_data, &imu_physical_data);


        const int64_t current_time = esp_timer_get_time();
        float dt = (float)(current_time - last_time) / 1000000.0f; // convert to seconds
        last_time = current_time;

        // Guard against a silly dt after a scheduling hiccup - a huge dt would produce a huge
        // derivative and integrator step in the cascade.
        if (dt <= 0.0f || dt > 0.02f) {
            dt = 1.0f / 1000.0f;
        }

        imu_compute_roll_pitch(imu_physical_data.acc_x_g, imu_physical_data.acc_y_g, imu_physical_data.acc_z_g, &roll_angle, &pitch_angle);

        if (imu_data_mutex != NULL && xSemaphoreTake(imu_data_mutex, 0) == pdTRUE) {
            latest_imu_payload.acc_x = imu_physical_data.acc_x_g;
            latest_imu_payload.acc_y = imu_physical_data.acc_y_g;
            latest_imu_payload.acc_z = imu_physical_data.acc_z_g;
            latest_imu_payload.gyro_x = imu_physical_data.gyro_x_dps;
            latest_imu_payload.gyro_y = imu_physical_data.gyro_y_dps;
            latest_imu_payload.gyro_z = imu_physical_data.gyro_z_dps;
            latest_imu_payload.roll = roll_angle;
            latest_imu_payload.pitch = pitch_angle;
            latest_imu_payload.temperature = imu_physical_data.temp_C;
            xSemaphoreGive(imu_data_mutex);
        }
        // roll_angle_comp = ALPHA * (roll_angle_comp + imu_physical_data.gyro_x_dps * dt) + (1 - ALPHA) * roll_angle;
        // pitch_angle_comp = ALPHA * (pitch_angle_comp + imu_physical_data.gyro_y_dps * dt) + (1 - ALPHA) * pitch_angle;

        // 1. Fuse accelerometer and gyro into an attitude estimate.
        attitude_update(&imu_physical_data, dt);
        attitude_get(&attitude);

        // 2. Pick up the latest navigation state from sensor_task. Zero-timeout: if the mutex
        //    is busy we keep last iteration's copy rather than blocking the 1 kHz loop.
        sensor_task_get_nav_state(&nav_state);

        // 3. Run the cascade, the arming state machine and the mixer. This writes the motors,
        //    including forcing them to zero on every disarmed path.
        flight_control_update(&attitude, &nav_state, dt);

        // Așteaptă exact până la următoarea milisecundă
        vTaskDelayUntil(&xLastWakeTime, xFreq);
    }
}

// THE 50 Hz LINK TASK. Core 0. Everything that talks to the telemetry module happens here.
//
// TRANSMIT ORDER IS DELIBERATE: status frame, then PID debug, then (every 5th cycle) the raw IMU
// frame. The status frame is what the dashboard and the pilot depend on, so it goes out first no
// matter how much tuning traffic is queued behind it.
//
// RECEIVE DRAINS THE WHOLE BUFFER rather than taking one frame per cycle - otherwise RX backs up
// and the control frames actually acted on get progressively staler. It uses the RESYNC reader
// so one corrupted byte costs a single frame instead of a full flush, because a flush would take
// good control frames with it and trip flight_control's 300 ms link watchdog.
//
// Every inbound handler length-checks payload_len against its struct before casting. That check
// is the only thing between a truncated frame and a read past the end of the payload buffer.
void telemetry_task(void *args) {
    //init uart...
    ESP_LOGI(TAG, "Telemtry transmission task started on core %d", xPortGetCoreID());

    telemetry_message_t rx_message;
    uint32_t cycle = 0;

    for (;;) {
        // --- Status frame, every cycle (50 Hz) -----------------------------
        // This is what the dashboard reads back: attitude, nav, motors, arming and the
        // validity flags.
        telemetry_status_payload_t status;
        flight_control_get_status(&status);

        esp_err_t send_error = uart_telemetry_send_message(
            TELEMETRY_MSG_STATUS,
            &status,
            sizeof(status)
        );
        if (send_error != ESP_OK) {
            ESP_LOGE(TAG, "Status telemetry send failed: %s", esp_err_to_name(send_error));
        }

        // --- PID debug samples ---------------------------------------------
        // Sent after the status frame and before the IMU frame: the status frame is what the
        // dashboard and the link watchdog depend on, so it goes out first regardless of how much
        // tuning traffic is queued behind it.
        //
        // Bounded drain. Nothing here blocks on the queue (zero wait) - an empty queue ends the
        // loop immediately, which is the normal case when no loop is subscribed.
        telemetry_pid_debug_payload_t pid_sample;
        for (int i = 0; i < PID_DEBUG_PER_CYCLE; i++) {
            if (!pid_registry_pop_debug(&pid_sample, 0)) {
                break;
            }

            // Deliberately unlogged even on failure: this runs up to 32 times per cycle and a
            // per-sample log line would saturate the console UART on its own.
            uart_telemetry_send_message(TELEMETRY_MSG_PID_DEBUG, &pid_sample, sizeof(pid_sample));
        }

        // --- Raw IMU frame, every 5th cycle (10 Hz) ------------------------
        // Not needed for control; kept for logging and for the raw-data view.
        if ((cycle % 5) == 0) {
            telemetry_imu_payload_t imu_payload = {0};

            if (imu_data_mutex != NULL && xSemaphoreTake(imu_data_mutex, pdMS_TO_TICKS(1)) == pdTRUE) {
                imu_payload = latest_imu_payload;
                xSemaphoreGive(imu_data_mutex);
            }

            send_error = uart_telemetry_send_message(
                TELEMETRY_MSG_IMU,
                &imu_payload,
                sizeof(imu_payload)
            );
            if (send_error != ESP_OK) {
                ESP_LOGE(TAG, "IMU telemetry send failed: %s", esp_err_to_name(send_error));
            }
        }

        // --- Receive ---------------------------------------------------------
        // Drain everything queued rather than taking one frame per 20 ms cycle, otherwise the
        // RX buffer backs up and the control frames we act on get progressively staler.
        // The resync reader is used here: it discards one bad frame instead of flushing the
        // whole buffer, which matters because a flush would drop good control frames and
        // trip the 300 ms link watchdog.
        while (uart_telemetry_read_message_resync(&rx_message, 2)) {
            switch ((telemetry_msg_type_t)rx_message.header.msg_type) {
                case TELEMETRY_MSG_CONTROL: {
                    if (rx_message.header.payload_len < sizeof(telemetry_control_payload_t)) {
                        ESP_LOGW(TAG, "Short control frame: %u bytes", rx_message.header.payload_len);
                        break;
                    }
                    const telemetry_control_payload_t *control =
                        (const telemetry_control_payload_t *)rx_message.payload;

                    // Feeds the controller AND pets the link watchdog.
                    flight_control_set_control_input(control);
                    break;
                }
                case TELEMETRY_MSG_GAINS: {
                    if (rx_message.header.payload_len < sizeof(telemetry_gains_payload_t)) {
                        ESP_LOGW(TAG, "Short gains frame: %u bytes", rx_message.header.payload_len);
                        break;
                    }
                    const telemetry_gains_payload_t *gains =
                        (const telemetry_gains_payload_t *)rx_message.payload;
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
void app_main(void)
{
    ESP_LOGI(TAG, "System starting up...");

    esp_err_t error;

    imu_data_mutex = xSemaphoreCreateMutex();
    if (imu_data_mutex == NULL) {
        ESP_LOGE(TAG, "Failed to create IMU data mutex");
        return;
    }

    imu_ready_semaphore = xSemaphoreCreateBinary();
    if (imu_ready_semaphore == NULL) {
        ESP_LOGE(TAG, "Failed to create IMU ready semaphore");
        return;
    }

    // --- Motors first -------------------------------------------------------
    // Before anything else can command thrust, get the LEDC channels configured and driven to
    // zero. Note this does NOT protect against the gates floating between reset and this
    // line - that needs physical pull-downs, see the TODO in motor_driver.c.
    error = motor_driver_init();
    if (error != ESP_OK) {
        ESP_LOGE(TAG, "Motor driver init failed: %s", esp_err_to_name(error));
        return;
    }

#if MOTOR_BENCH_MODE
    // Bench mode owns the board from here. Nothing below this line runs, so no sensor, no
    // estimator and no control loop can touch the motors while the ramp is measuring them.
    motor_bench_run();
    return;
#endif

    // --- Battery monitor -----------------------------------------------------
    // NON-FATAL by design, unlike everything else in this block. Pack voltage is telemetry, not
    // control - nothing in the cascade reads it - so a dead ADC or an unfitted divider must not
    // stop the aircraft flying. On failure battery_monitor_get_volts() reports the same 3.8 V
    // nominal that flight_control.c hardcoded before the divider existed, which is exactly the
    // behaviour this firmware had for its whole life up to 2026-09-03.
    error = battery_monitor_init();
    if (error != ESP_OK) {
        ESP_LOGW(TAG, "Battery monitor unavailable (%s) - reporting nominal voltage",
                 esp_err_to_name(error));
    }

    // --- Attitude estimator --------------------------------------------------
    // tau = 0.5 s: the gyro carries the short-term response, the accelerometer trims the
    // long-term drift out.
    error = attitude_init(1.0f / 1000.0f, 0.5f);
    if (error != ESP_OK) {
        ESP_LOGE(TAG, "Attitude estimator init failed: %s", esp_err_to_name(error));
        return;
    }

    // --- Flight control ------------------------------------------------------
    error = flight_control_init();
    if (error != ESP_OK) {
        ESP_LOGE(TAG, "Flight control init failed: %s", esp_err_to_name(error));
        return;
    }

    // --- Telemetry link ------------------------------------------------------
    telemetry_uart_config_t uart_config = {
        .uart_port  = UART_NUM_1,
        .tx_pin     = GPIO_NUM_6,
        .rx_pin     = GPIO_NUM_7,
        .baud_rate  = 460800
    };

    error = uart_telemetry_init(&uart_config);
    if (error != ESP_OK) {
        ESP_LOGE(TAG, "Failed to initialize UART telemetry: %s", esp_err_to_name(error));
        return;
    }
    else {
        ESP_LOGI(TAG, "UART telemetry initialized successfully.");
    }

    // --- Control loop --------------------------------------------------------
    xTaskCreatePinnedToCore(
        fc_task,
        "Flight_Ctrl_Task",
        4096,
        NULL,
        configMAX_PRIORITIES - 1, //prioritatea cea mai mare, pentru a nu fi intrerupt de alte taskuri
        NULL,
        1
    );
    //Why core 1 for FC task ?
    //Core 0 -> PRO_CPU(PROTOCOL CPU): does run many background tasks like memory access, other OS related functions etc...
    //Core 1 -> APP_CPU(APPLICATION CPU): does run the application code, so we want our flight control task to run on this core to avoid any interruptions from background tasks.

    // --- Navigation sensors --------------------------------------------------
    // Wait for fc_task to finish imu_setup() and the calibration sweeps, because the VL53L1X
    // attaches to the I2C bus that imu_setup() creates. Accel calibration is 500 samples at
    // 2 ms (~1.5 s with the I2C reads), and the gyro sweep is 1000 samples and may retry up to
    // three times if it detects motion. The 2 ms delay rounds up at a 1 kHz tick and the I2C
    // read adds ~0.5 ms, so each sweep is nearer 3 s than 2 s: ~11 s worst case in total.
    // 30 s leaves room for that without the ToF ever starting mid-calibration.
    if (xSemaphoreTake(imu_ready_semaphore, pdMS_TO_TICKS(30000)) != pdTRUE) {
        ESP_LOGE(TAG, "IMU never became ready - navigation sensors will not be started");
    } else {
        error = sensor_task_init();
        if (error != ESP_OK) {
            ESP_LOGE(TAG, "Sensor task init failed: %s", esp_err_to_name(error));
        } else {
            error = sensor_task_start(0);
            if (error != ESP_OK) {
                ESP_LOGE(TAG, "Failed to start sensor task: %s", esp_err_to_name(error));
            }
        }
    }

    xTaskCreatePinnedToCore(
        telemetry_task,
        "Telemetry_Task",
        4096,
        NULL,
        5,
        NULL,
        0
    );
}

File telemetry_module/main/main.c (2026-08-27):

// main.c - the telemetry module's entry point. app_main() and nothing else.
//
// WHAT THIS FILE DOES
//   Every subsystem lives in a component; this file's only job is to bring them up in the right
//   ORDER and put them on the right CORE. Both are load-bearing, so both are documented below.
//
// HOW THE ORDER IS DECIDED
//   Dependency first, priority second: control_state (depends on nothing) -> UART link (the thing
//   that actually flies the drone, before Wi-Fi) -> camera/SD -> Wi-Fi AP -> gs_link (needs a
//   netif) -> HTTP server LAST, because it is what starts accepting pilot input and everything it
//   touches must already exist.
//
// FATAL vs NON-FATAL IS A DELIBERATE SPLIT
//   Fatal:     control_state, uart_link, wifi_ap, http_server  - the pilot cannot fly without them.
//   Non-fatal: camera_sd, gs_link                              - they only make the drone more useful.
//   The flight controller applies the same principle to its ToF and optical flow sensors.
//
// Core assignment and the priority ladder are explained in the comment block below.

#include <stdio.h>
#include "freertos/FreeRTOS.h"
#include "freertos/task.h"
#include "esp_log.h"

#include "wifi_ap.h"
#include "control_state.h"
#include "uart_link.h"
#include "camera_sd.h"
#include "http_server.h"
#include "gs_link.h"

static const char *TAG = "TELEMETRY_MODULE";

// CORE ASSIGNMENT
//
// Core 0: Wi-Fi and lwIP (which the IDF pins there anyway), the HTTP server, and both UART
//         tasks. Keeping the whole control path on one core means the 50 Hz transmit cadence
//         and the 20 Hz input POSTs are scheduled against each other by one scheduler, with
//         no cross-core latency in between.
//
// Core 1: the camera capture task, alone. Grabbing a UXGA JPEG out of PSRAM and pushing it
//         through FATFS onto an SD card is a long, bursty, blocking job. Isolating it on the
//         other core means a slow card cannot delay a control frame no matter how long it
//         takes.
#define CORE_CONTROL 0
#define CORE_CAMERA 1

void app_main(void) {
    ESP_LOGI(TAG, "Telemetry module starting up...");

    esp_err_t error;

    // --- 1. Control state ----------------------------------------------------
    // First, so that every later module has somewhere valid to read from and write to.
    error = control_state_init();
    if (error != ESP_OK) {
        ESP_LOGE(TAG, "Control state init failed: %s", esp_err_to_name(error));
        return;
    }

    // --- 2. UART link to the flight controller -------------------------------
    // Before Wi-Fi: this is the link that actually flies the drone, and if it cannot come up
    // there is no point serving a dashboard.
    error = uart_link_init();
    if (error != ESP_OK) {
        ESP_LOGE(TAG, "UART link init failed: %s", esp_err_to_name(error));
        return;
    }

    error = uart_link_start(CORE_CONTROL);
    if (error != ESP_OK) {
        ESP_LOGE(TAG, "Failed to start UART tasks: %s", esp_err_to_name(error));
        return;
    }

    // --- 3. Camera and SD card -----------------------------------------------
    // NON-FATAL BY DESIGN. A missing SD card or a failed camera probe must not stop the drone
    // flying - photography is the mission, but flight is the prerequisite. Errors here are
    // logged, surfaced on the dashboard, and otherwise ignored.
    error = camera_sd_init();
    if (error != ESP_OK) {
        ESP_LOGW(TAG, "Camera/SD not fully available (%s) - continuing, the drone can still fly",
                 esp_err_to_name(error));
    }

    // Started even if init partly failed: camera_sd_request_capture() rejects requests on its
    // own when the hardware is missing, and having the task running keeps the shutdown paths
    // uniform.
    error = camera_sd_start_task(CORE_CAMERA);
    if (error != ESP_OK) {
        ESP_LOGW(TAG, "Failed to start capture task: %s", esp_err_to_name(error));
    }

    // --- 4. Wi-Fi SoftAP -----------------------------------------------------
    error = wifi_ap_init();
    if (error != ESP_OK) {
        ESP_LOGE(TAG, "Wi-Fi AP init failed: %s", esp_err_to_name(error));
        return;
    }

    // --- 5. Ground station link ----------------------------------------------
    // NON-FATAL, same reasoning as the camera: this is a tuning tool, not a flight requirement.
    // Started after the AP so lwIP has a netif to bind to, and before the HTTP server only
    // because the HTTP server is the thing that starts accepting pilot input.
    error = gs_link_start();
    if (error != ESP_OK) {
        ESP_LOGW(TAG, "Ground station link unavailable (%s) - PID tuning over UDP is disabled",
                 esp_err_to_name(error));
    }

    // --- 6. HTTP server ------------------------------------------------------
    // Last, because it is the thing that starts accepting pilot input, and everything it
    // touches has to exist before the first request arrives.
    error = http_server_start();
    if (error != ESP_OK) {
        ESP_LOGE(TAG, "HTTP server failed to start: %s", esp_err_to_name(error));
        return;
    }

    ESP_LOGI(TAG, "Startup complete.");
    ESP_LOGI(TAG, "  Connect to Wi-Fi '%s' and open http://192.168.4.1/", WIFI_AP_SSID);
    ESP_LOGI(TAG, "  Camera: %s   SD card: %s",
             camera_sd_camera_ok() ? "OK" : "UNAVAILABLE",
             camera_sd_sd_ok() ? "OK" : "UNAVAILABLE");
}

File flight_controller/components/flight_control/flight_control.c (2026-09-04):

// flight_control.c - the cascade, the mixer, the arming machine and the link watchdog.
//
// LAYOUT OF THIS FILE, in order
//   1. Loop rates and dividers          - how 1 kHz becomes 250 Hz and 50 Hz
//   2. Safety constants                 - link timeout, arming threshold, idle floor
//   3. Default PID gains                - all starting points, all live-tunable
//   4. Module state                     - the eight PIDs, arming state, inter-loop setpoints
//   5. pid_loop_to_telemetry[]          - the ONLY place the two loop-id orderings meet
//   6. flight_control_run_pid()         - every PID call in the cascade goes through this
//   7. flight_control_mix()             - the X-quad mixer and its three-step throttle placement
//   8. flight_control_update_arming()   - kill latch, watchdog, four-condition arming gate
//   9. outer / mid / inner loop bodies
//  10. flight_control_update()          - the 1 kHz entry point that drives 6-9
//  11. status assembly and the gain setters
//
// HOW THE PIECES FIT
//   flight_control_update() is called at 1 kHz and does everything in one call stack: snapshot
//   the control frame, evaluate arming, then run whichever loops this tick is due for. The
//   dividers are tested BEFORE tick_counter is incremented, so tick 0 after arming runs all
//   three - otherwise the mixer would spin up on a throttle_command the pilot never set.
//
//   Setpoints flow downward through module statics (outer writes angle_setpoint_*, mid writes
//   rate_setpoint_*, inner consumes them). That is safe precisely because all three run in the
//   same task on the same tick - there is no cross-task handoff anywhere inside the cascade.
//
// WHAT MAY AND MAY NOT BLOCK
//   Nothing in this file blocks. The only cross-task entry point is
//   flight_control_set_control_input(), which runs on core 0 while the cascade runs on core 1 and
//   is protected by a portMUX spinlock - a torn read there would mean acting on half of one frame
//   and half of another (new throttle, old kill flag). The single log in the inner loop is
//   rate-limited to once a second so a failing motor write cannot flood at 1 kHz.
//
// BEFORE FLYING: the mixer signs, MOTOR_IDLE_THRUST and HOVER_THROTTLE are all unverified. Each
// is marked at its definition and the bench procedures are in README.md.

#include "flight_control.h"
#include "pid_controller.h"
#include "pid_registry.h"
#include "motor_driver.h"
#include "battery_monitor.h"
#include "freertos/FreeRTOS.h"
#include "freertos/task.h"
#include "esp_timer.h"
#include "esp_log.h"
#include <math.h>
#include <string.h>

static const char *TAG = "FLIGHT_CTRL";

// ---------------------------------------------------------------------------
// Loop rates. The inner loop runs on every fc_task tick; the others are derived from it with
// divider counters so that all three stay phase-locked and no loop can drift relative to
// another.
// ---------------------------------------------------------------------------
#define INNER_LOOP_HZ 1000
#define MID_LOOP_DIVIDER   4    // 1000 / 4  = 250 Hz angle loop
#define OUTER_LOOP_DIVIDER 20   // 1000 / 20 =  50 Hz altitude and velocity loops

#define MID_LOOP_DT   ((float)MID_LOOP_DIVIDER / (float)INNER_LOOP_HZ)     // 0.004 s
#define OUTER_LOOP_DT ((float)OUTER_LOOP_DIVIDER / (float)INNER_LOOP_HZ)   // 0.020 s

// ---------------------------------------------------------------------------
// SAFETY CONSTANTS
// ---------------------------------------------------------------------------

// Control-link watchdog. No valid control frame inside this window and we disarm.
// The telemetry module sends at a fixed 50 Hz (20 ms), so 300 ms tolerates 15 lost frames
// before acting - long enough to ride out Wi-Fi hiccups, short enough to matter.
#define LINK_TIMEOUT_US 300000

// Arming gate: the throttle stick must be genuinely down, not just low.
#define ARM_THROTTLE_THRESHOLD 0.02f

// Below this throttle the motors are held off even when armed. Prevents the integrators
// winding up while the drone sits on the floor with the props barely turning.
#define MOTOR_IDLE_THRESHOLD 0.05f
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

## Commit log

2025-11-12 got 4 leds which i can control with 2 js s on a web page
2025-12-07 uploaded pcb kicad prj
    [tinywhoop_frame.kicad_pcb, tinywhoop_frame.kicad_sch]
2025-12-08 pcb updates, created fab files
    [tinywhoop_frame-B_Cu.gbl, tinywhoop_frame-B_Mask.gbs, tinywhoop_frame-B_Paste.gbp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]
2025-12-08 pcb updates
    [tinywhoop_frame-B_Cu.gbl, tinywhoop_frame-B_Mask.gbs, tinywhoop_frame-B_Paste.gbp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]
2025-12-10 updated pcb
    [tinywhoop_frame.kicad_pcb, tinywhoop_frame.kicad_sch]
2025-12-10 pcb update
    [tinywhoop_frame.kicad_pcb]
2026-07-10 created new imu driver component
2026-07-12 added imu documents
2026-07-12 started imu driver implementation
2026-07-13 finished imu driver read and setup functions
2026-07-14 implemented convert function for imu raw data
2026-07-14 implemented gyro calibration function
2026-07-18 implemented acc calibration function
2026-07-18 tried gyro compensation, not convinced i m gonna use that
2026-07-18 moved roll and pitch calculation to imu_driver
2026-07-18 compared roll and pitch values with and without acc calibration
2026-07-18 corrected acc calibration function
    [imu_driver.c]
2026-07-18 tried imu acc calibration function again, i will stick with it for now
2026-07-19 implemented uart telemtry component
2026-07-19 xiao esp32 s3 sense pinout
2026-07-20 modified main to send imu data and receive control data to/from telemetry module
2026-07-20 modified main to receive imu data and send dummy controll data to/from flight controller
2026-07-21 moved telemetry uart component to shared_components folder so both projects have access to the same component
2026-07-23 Create motor driver empty component
2026-07-26 created new webpage, added more camera functionalaties, added drone controls
    [partitions.csv]
2026-08-05 flight controller implementation(may need improvements)
    [partitions.csv]
2026-08-08 modified motor mixer
2026-08-08 changed throttle increment, displayed throttle trim value in dashboard
2026-08-10 tof sensor calibration offset calculation project
2026-08-10 ground station
2026-08-27 Add UDP ground station link component and related functionalities
    - Implement gs_link.c and gs_link.h for UDP communication between the flight controller and ground station.
    - Introduce functions for starting the link, handling incoming datagrams, and forwarding telemetry messages.
    - Create a mutex for managing peer addresses and a queue for uplink messages.
    - Add README documentation for the http_server, uart_link, wifi_ap, and main components detailing their functionalities and interactions.
    - Establish core assignment and startup order for the main application to ensure proper initialization of components.
2026-08-27 modified pitch and roll buttons behaviour. changed from ramp to a kick
2026-09-05 tinywhoop schematic
    [tinywhoop_sch.kicad_pcb, tinywhoop_sch.kicad_sch]
2026-09-05 generated pdf schematic
